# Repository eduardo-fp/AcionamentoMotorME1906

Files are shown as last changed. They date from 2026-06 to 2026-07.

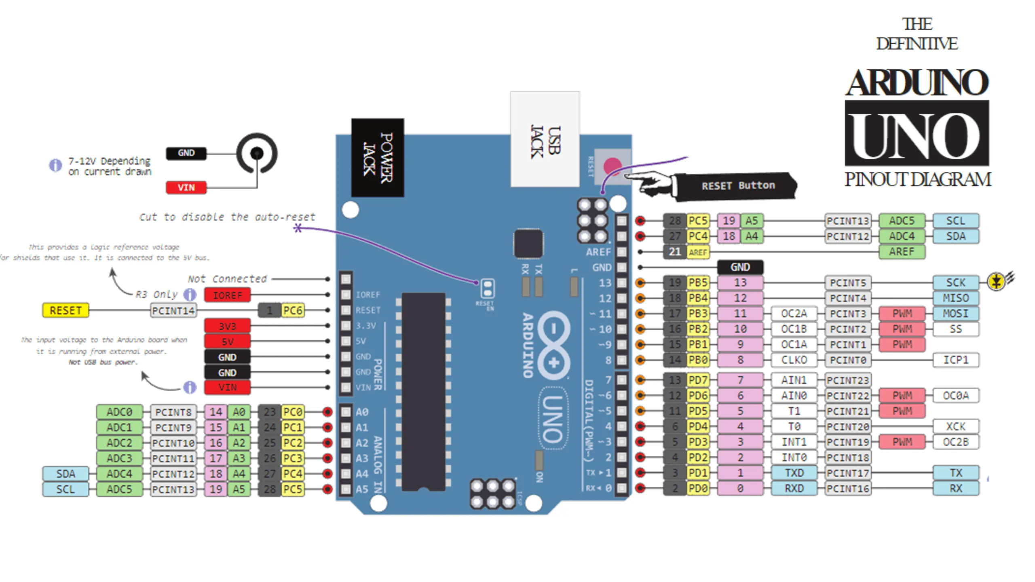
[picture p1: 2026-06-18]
Docs/ArduinoPinout.png

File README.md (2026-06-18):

# 🚀 Arduino Full-Bridge Shield: Acionamento de Potência para Motor ME19006 (ME0909)

O objetivo principal é criar uma ponte completa (*Full-Bridge*) robusta e didática para realizar ensaios de eficiência e testes de técnicas avançadas de modulação chaveada no motor **ME19006 (ME0909)**, utilizado no barco da equipe de corrida **Zênite Solar (IFSC)**.

A arquitetura foi pensada em formato Shield para o ecossistema Arduino, facilitando a troca rápida de códigos de controle e aquisição de dados durante as bancadas de teste.

## 📋 Especificações do Sistema

O projeto foi dimensionado para operar nas condições reais de teste da equipe de barco solar, trabalhando com alta margem de segurança elétrica e térmica:

| **Parâmetro / Componente** | **Especificação** | **Descrição / Justificativa** |
| :--- | :--- | :--- |
| **Tensão de Barramento** | `60V DC` | Tensão nominal de alimentação do barramento de tração do barco da equipe **Zênite Solar (IFSC)**. |
| **Corrente Máxima** | `50A` | Corrente máxima de teste estipulada para validação das modulações do TCC. |
| **Motor Alvo** | `ME19006 (ME0909)` | Motor utilizado no barco da equipe Zenite Solar (IFSC). |
| **Gate Driver** | `MP1923` | Driver Half-Bridge de 100V. Fornece 7A/8A de pico. |
| **MOSFET de Potência** | `IXFN420N10T` | MOSFET utilizado no barco da equipe Zenite Solar(IFSC). |
| **Frequência de Chaveamento** | `6 kHz a 12 kHz` | Faixa de frequência de modulação otimizada para o motor e para minimizar perdas no driver. |

## 🛡️ Destaques de Projeto da PCB

Para garantir que a placa funcione de forma estável sob correntes de 50A e barramento de 60V, as seguintes proteções e metodologias foram implementadas no layout:

1. **Rede de Bootstrap Otimizada:** Dimensionada utilizando o pior caso de chaveamento (**6 kHz**). Capacitores cerâmicos SMD de **4.7 µF (50V X7R)** foram selecionados para compensar as correntes quiescentes do driver e a perda de capacitância por efeito de *DC Bias*.

2. **Filtros Snubber RC:** Integrados fisicamente rentes aos drenos e fontes dos MOSFETs IXFN420N10T para mitigar os picos de sobretensão causados pela indutância parasita das trilhas na comutação.

3. **Dimensionamento de Trilhas de Potência:** Áreas de cobre superdimensionadas e estanhadas para suportar a densidade de corrente de 50A sem elevação excessiva de temperatura (calculado via IPC-2152).

## 📂 Estrutura do Repositório

O repositório está organizado para facilitar a replicação, fabricação e auditoria do projeto:

```text
📦 AcionamentoMotorME1906
 ┣ 📂 Hardware
 ┃ ┣ 📜 Esquemático (Arquivos fontes e PDF)
 ┃ ┣ 📜 PCB Layout (Arquivos de design e Gerbers para fabricação)
 ┃ ┣ 📜 BOM_Custos.csv (Lista de Materials e Orçamento do Projeto)
 ┃ ┗ 📜 Modelos 3D (Arquivos STEP para integração mecânica do Shield)
 ┣ 📂 Docs
 ┃ ┣ 📜 Calculos (Bootstrap, Snubber e dimensionamento de trilhas)
 ┃ ┗ 📜 Datasheets (Documentações técnicas do MP1923 e IXFN420N10T)
 ┣ 📂 Software
 ┃ ┗ 📜 Codigos Arduino (Implementação das rotinas de controle e PWM)
 ┗ 📜 README.md

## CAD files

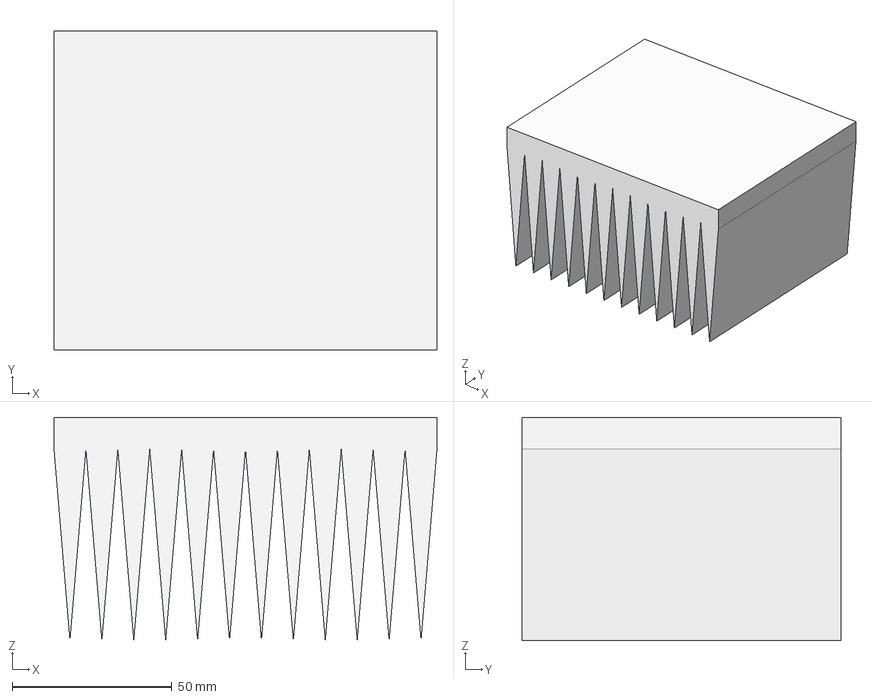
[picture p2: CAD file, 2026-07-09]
Biblioteca/DissipadorBarco.step
120.0 x 100.0 x 70.0 mm

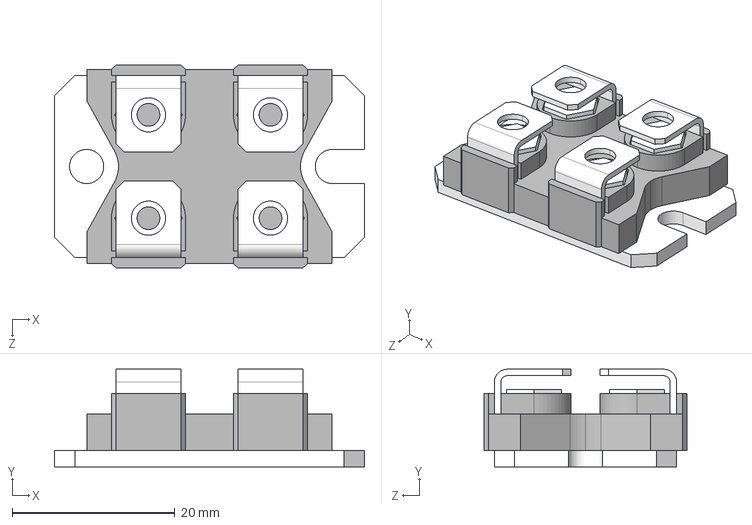
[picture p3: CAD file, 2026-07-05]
Biblioteca/User Library-SOT-227B.step
38.1 x 12.0 x 24.9 mm

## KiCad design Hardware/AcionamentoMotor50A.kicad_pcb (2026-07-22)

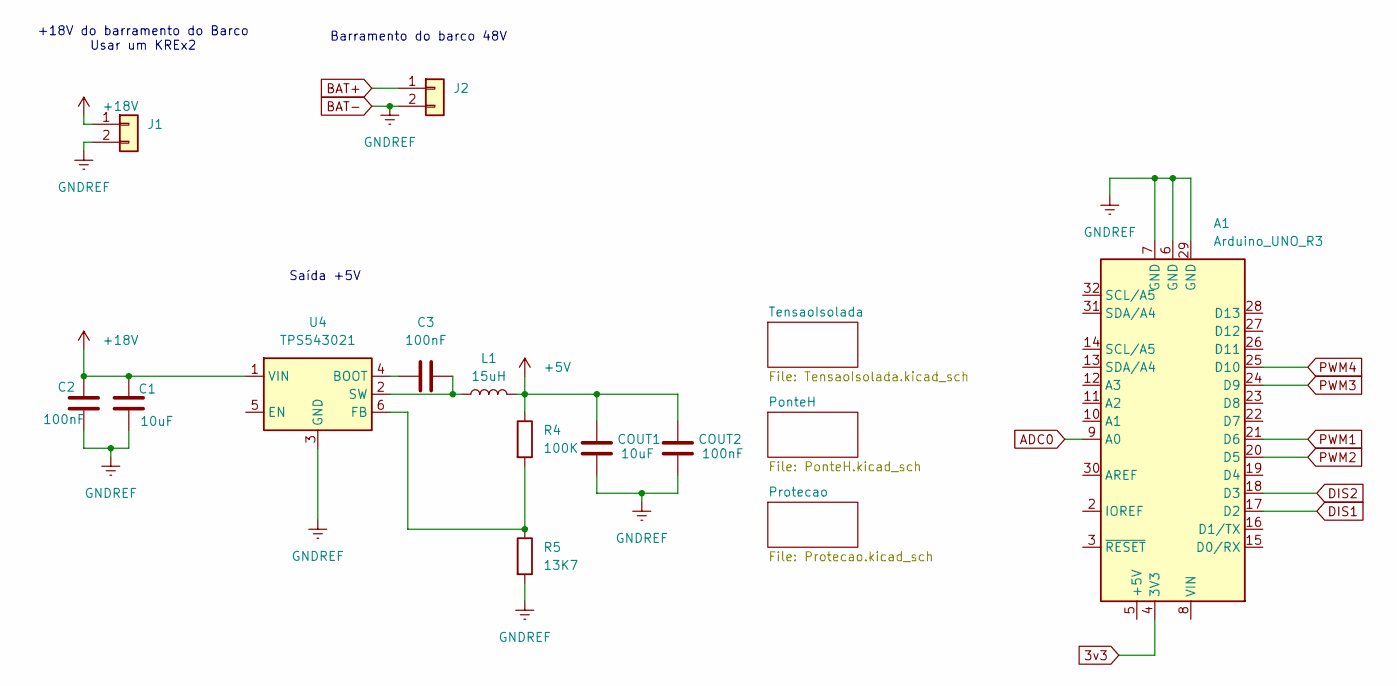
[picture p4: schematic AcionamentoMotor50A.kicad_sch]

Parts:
A1: Arduino_UNO_R3
C1: 10uF; C_0805_2012Metric_Pad1.18x1.45mm_HandSolder
C2, C3: 100nF; C_0805_2012Metric_Pad1.18x1.45mm_HandSolder
COUT1: 10uF; C_0805_2012Metric_Pad1.18x1.45mm_HandSolder
COUT2: 100nF; C_0805_2012Metric_Pad1.18x1.45mm_HandSolder
J1, J2: Conn_01x02; TerminalBlock_Phoenix_MKDS-1,5-2_1x02_P5.00mm_Horizontal
L1: 15uH; L_0805_2012Metric_Pad1.05x1.20mm_HandSolder
R4: 100K; R_0805_2012Metric_Pad1.20x1.40mm_HandSolder
R5: 13K7; R_0805_2012Metric_Pad1.20x1.40mm_HandSolder
U4: TPS543021; SOT-563

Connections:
3v3: A1.4 (3V3)
5V: COUT1.2, COUT2.2, L1.2, R4.1; also elsewhere on the board
+18V: C1.1, C2.1, J1.1, U4.1 (VIN); also elsewhere on the board
ADC0: A1.9 (A0); also elsewhere on the board
BAT+: J2.1; also elsewhere on the board
BAT-: A1.6 (GND), A1.7 (GND), A1.29 (GND), C1.2, C2.2, COUT1.1, COUT2.1, J1.2, J2.2, R5.2, U4.3 (GND); also elsewhere on the board
DIS1: A1.17 (D2); also elsewhere on the board
DIS2: A1.18 (D3); also elsewhere on the board
unnamed: C3.1, U4.4 (BOOT)
unnamed: R4.2, R5.1, U4.6 (FB)
unnamed: C3.2, L1.1, U4.2 (SW)
PWM1: A1.21 (D6); also elsewhere on the board
PWM2: A1.20 (D5); also elsewhere on the board
PWM3: A1.24 (D9); also elsewhere on the board
PWM4: A1.25 (D10); also elsewhere on the board

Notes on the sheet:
Saída +5V
Barramento do barco 48V
+18V do barramento do Barco Usar um KREx2

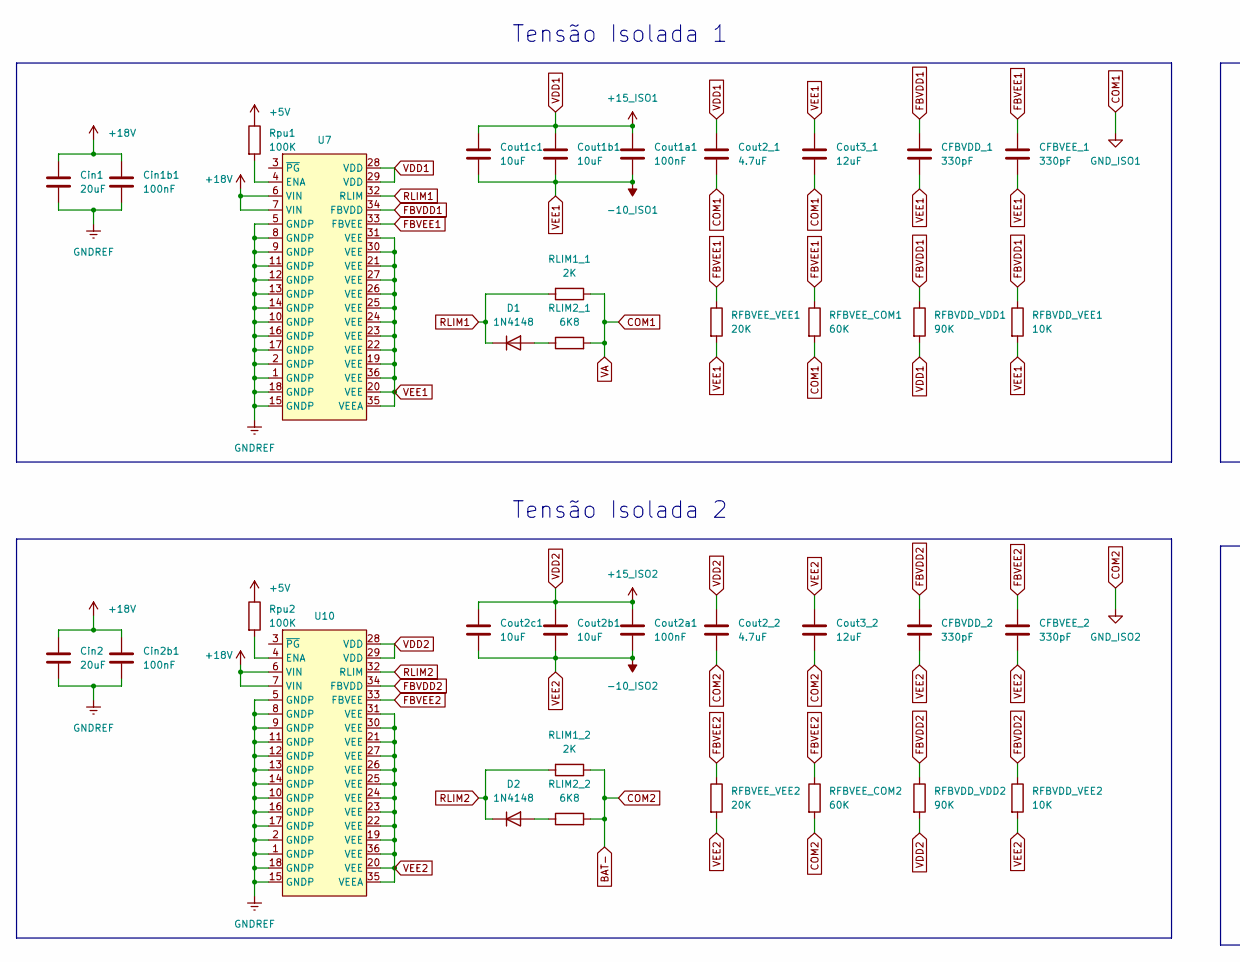
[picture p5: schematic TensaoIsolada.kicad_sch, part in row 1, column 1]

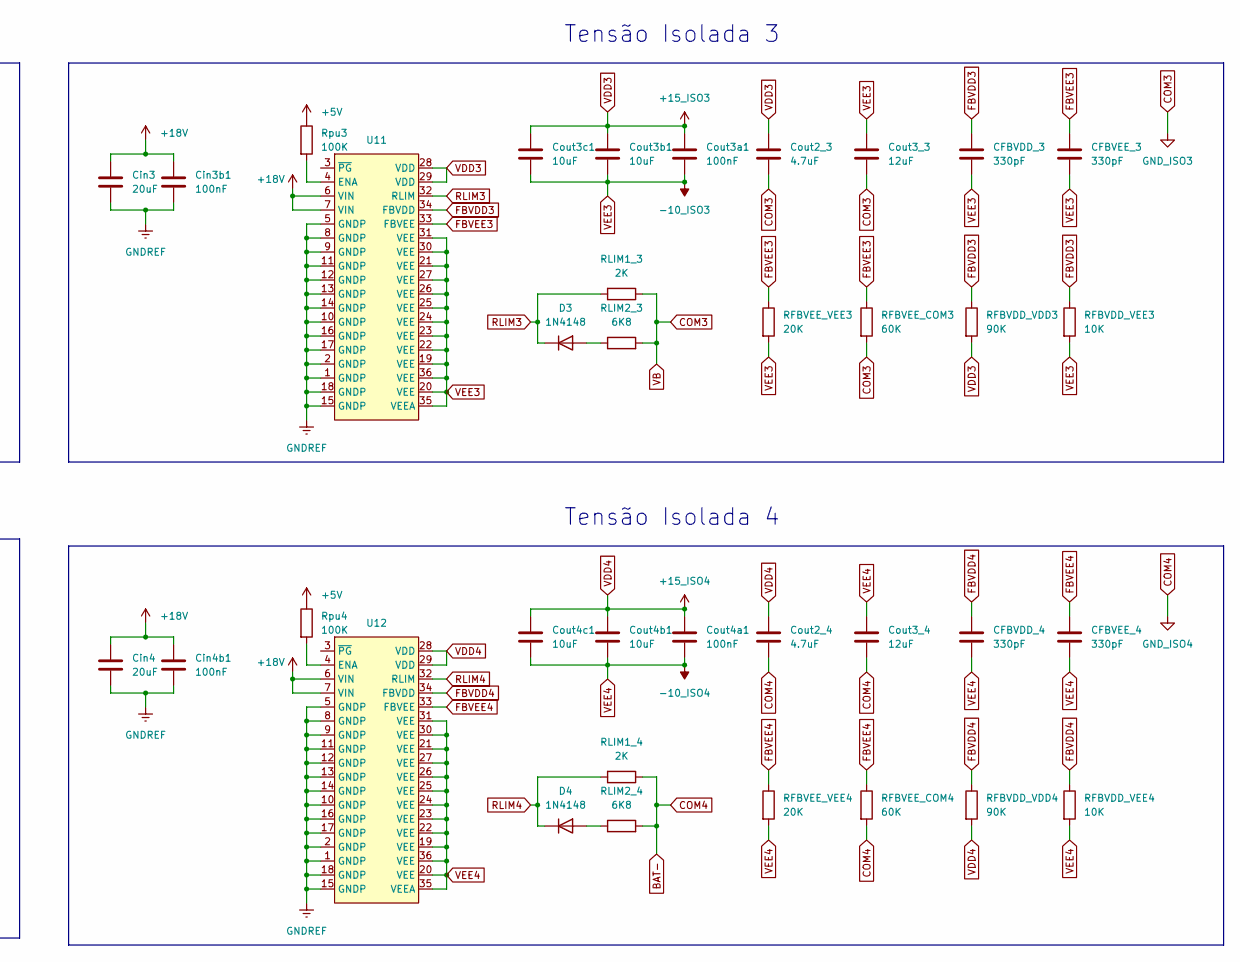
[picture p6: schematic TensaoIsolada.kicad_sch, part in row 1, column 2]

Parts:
CFBVDD_1, CFBVDD_2, CFBVDD_3, CFBVDD_4: 330pF; C_0805_2012Metric_Pad1.18x1.45mm_HandSolder
CFBVEE_1, CFBVEE_2, CFBVEE_3, CFBVEE_4: 330pF; C_0805_2012Metric_Pad1.18x1.45mm_HandSolder
Cin1, Cin2, Cin3, Cin4: 20uF; C_0805_2012Metric_Pad1.18x1.45mm_HandSolder
Cin1b1, Cin2b1, Cin3b1, Cin4b1: 100nF; C_0805_2012Metric_Pad1.18x1.45mm_HandSolder
Cout1a1, Cout2a1, Cout3a1, Cout4a1: 100nF; C_0805_2012Metric_Pad1.18x1.45mm_HandSolder
Cout1b1, Cout1c1, Cout2b1, Cout2c1, Cout3b1, Cout3c1, Cout4b1, Cout4c1: 10uF; C_0805_2012Metric_Pad1.18x1.45mm_HandSolder
Cout2_1, Cout2_2, Cout2_3, Cout2_4: 4.7uF; C_0805_2012Metric_Pad1.18x1.45mm_HandSolder
Cout3_1, Cout3_2, Cout3_3, Cout3_4: 12uF; C_0805_2012Metric_Pad1.18x1.45mm_HandSolder
D1, D2, D3, D4: 1N4148; D_DO-35_SOD27_P7.62mm_Horizontal
RFBVDD_VDD1, RFBVDD_VDD2, RFBVDD_VDD3, RFBVDD_VDD4: 90K; R_0805_2012Metric_Pad1.20x1.40mm_HandSolder
RFBVDD_VEE1, RFBVDD_VEE2, RFBVDD_VEE3, RFBVDD_VEE4: 10K; R_0805_2012Metric_Pad1.20x1.40mm_HandSolder
RFBVEE_COM1, RFBVEE_COM2, RFBVEE_COM3, RFBVEE_COM4: 60K; R_0805_2012Metric_Pad1.20x1.40mm_HandSolder
RFBVEE_VEE1, RFBVEE_VEE2, RFBVEE_VEE3, RFBVEE_VEE4: 20K; R_0805_2012Metric_Pad1.20x1.40mm_HandSolder
RLIM1_1, RLIM1_2, RLIM1_3, RLIM1_4: 2K; R_0805_2012Metric_Pad1.20x1.40mm_HandSolder
RLIM2_1, RLIM2_2, RLIM2_3, RLIM2_4: 6K8; R_0805_2012Metric_Pad1.20x1.40mm_HandSolder
Rpu1, Rpu2, Rpu3, Rpu4: 100K; R_0805_2012Metric_Pad1.20x1.40mm_HandSolder
U7, U10, U11, U12: SSOP-36

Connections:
5V: Rpu1.1, Rpu2.1, Rpu3.1, Rpu4.1; also elsewhere on the board
+18V: Cin1.1, Cin1b1.1, Cin2.1, Cin2b1.1, Cin3.1, Cin3b1.1, Cin4.1, Cin4b1.1, U7.6 (VIN), U7.7 (VIN), U10.6 (VIN), U10.7 (VIN), U11.6 (VIN), U11.7 (VIN), U12.6 (VIN), U12.7 (VIN); also elsewhere on the board
BAT-: Cin1.2, Cin1b1.2, Cin2.2, Cin2b1.2, Cin3.2, Cin3b1.2, Cin4.2, Cin4b1.2, Cout2_2.2, Cout2_4.2, Cout3_2.2, Cout3_4.2, RFBVEE_COM2.2, RFBVEE_COM4.2, RLIM1_2.1, RLIM1_4.1, RLIM2_2.2, RLIM2_4.2, U7.1 (GNDP), U7.2 (GNDP), U7.5 (GNDP), U7.8 (GNDP), U7.9 (GNDP), U7.10 (GNDP), U7.11 (GNDP), U7.12 (GNDP), U7.13 (GNDP), U7.14 (GNDP), U7.15 (GNDP), U7.16 (GNDP), U7.17 (GNDP), U7.18 (GNDP), U10.1 (GNDP), U10.2 (GNDP), U10.5 (GNDP), U10.8 (GNDP), U10.9 (GNDP), U10.10 (GNDP), U10.11 (GNDP), U10.12 (GNDP), U10.13 (GNDP), U10.14 (GNDP), U10.15 (GNDP), U10.16 (GNDP), U10.17 (GNDP), U10.18 (GNDP), U11.1 (GNDP), U11.2 (GNDP), U11.5 (GNDP), U11.8 (GNDP), U11.9 (GNDP), U11.10 (GNDP), U11.11 (GNDP), U11.12 (GNDP), U11.13 (GNDP), U11.14 (GNDP), U11.15 (GNDP), U11.16 (GNDP), U11.17 (GNDP), U11.18 (GNDP), U12.1 (GNDP), U12.2 (GNDP), U12.5 (GNDP), U12.8 (GNDP), U12.9 (GNDP), U12.10 (GNDP), U12.11 (GNDP), U12.12 (GNDP), U12.13 (GNDP), U12.14 (GNDP), U12.15 (GNDP), U12.16 (GNDP), U12.17 (GNDP), U12.18 (GNDP); also elsewhere on the board
COM1: Cout2_1.2, Cout3_1.2, RFBVEE_COM1.2, RLIM1_1.1, RLIM2_1.2; also elsewhere on the board
COM3: Cout2_3.2, Cout3_3.2, RFBVEE_COM3.2, RLIM1_3.1, RLIM2_3.2; also elsewhere on the board
FBVDD1: CFBVDD_1.1, RFBVDD_VDD1.1, RFBVDD_VEE1.1, U7.34 (FBVDD)
FBVDD2: CFBVDD_2.1, RFBVDD_VDD2.1, RFBVDD_VEE2.1, U10.34 (FBVDD)
FBVDD3: CFBVDD_3.1, RFBVDD_VDD3.1, RFBVDD_VEE3.1, U11.34 (FBVDD)
FBVDD4: CFBVDD_4.1, RFBVDD_VDD4.1, RFBVDD_VEE4.1, U12.34 (FBVDD)
FBVEE1: CFBVEE_1.1, RFBVEE_COM1.1, RFBVEE_VEE1.1, U7.33 (FBVEE)
FBVEE2: CFBVEE_2.1, RFBVEE_COM2.1, RFBVEE_VEE2.1, U10.33 (FBVEE)
FBVEE3: CFBVEE_3.1, RFBVEE_COM3.1, RFBVEE_VEE3.1, U11.33 (FBVEE)
FBVEE4: CFBVEE_4.1, RFBVEE_COM4.1, RFBVEE_VEE4.1, U12.33 (FBVEE)
unnamed: D1.2 (A), RLIM2_1.1
unnamed: D2.2 (A), RLIM2_2.1
unnamed: D3.2 (A), RLIM2_3.1
unnamed: D4.2 (A), RLIM2_4.1
unnamed: Rpu1.2, U7.4 (ENA)
unnamed: Rpu2.2, U10.4 (ENA)
unnamed: Rpu3.2, U11.4 (ENA)
unnamed: Rpu4.2, U12.4 (ENA)
RLIM1: D1.1 (K), RLIM1_1.2, U7.32 (RLIM)
RLIM2: D2.1 (K), RLIM1_2.2, U10.32 (RLIM)
RLIM3: D3.1 (K), RLIM1_3.2, U11.32 (RLIM)
RLIM4: D4.1 (K), RLIM1_4.2, U12.32 (RLIM)
VDD1: Cout1a1.1, Cout1b1.1, Cout1c1.1, Cout2_1.1, RFBVDD_VDD1.2, U7.28 (VDD), U7.29 (VDD); also elsewhere on the board
VDD2: Cout2_2.1, Cout2a1.1, Cout2b1.1, Cout2c1.1, RFBVDD_VDD2.2, U10.28 (VDD), U10.29 (VDD); also elsewhere on the board
VDD3: Cout2_3.1, Cout3a1.1, Cout3b1.1, Cout3c1.1, RFBVDD_VDD3.2, U11.28 (VDD), U11.29 (VDD); also elsewhere on the board
VDD4: Cout2_4.1, Cout4a1.1, Cout4b1.1, Cout4c1.1, RFBVDD_VDD4.2, U12.28 (VDD), U12.29 (VDD); also elsewhere on the board
VEE1: CFBVDD_1.2, CFBVEE_1.2, Cout1a1.2, Cout1b1.2, Cout1c1.2, Cout3_1.1, RFBVDD_VEE1.2, RFBVEE_VEE1.2, U7.19 (VEE), U7.20 (VEE), U7.21 (VEE), U7.22 (VEE), U7.23 (VEE), U7.24 (VEE), U7.25 (VEE), U7.26 (VEE), U7.27 (VEE), U7.30 (VEE), U7.31 (VEE), U7.35 (VEEA), U7.36 (VEE); also elsewhere on the board
VEE2: CFBVDD_2.2, CFBVEE_2.2, Cout2a1.2, Cout2b1.2, Cout2c1.2, Cout3_2.1, RFBVDD_VEE2.2, RFBVEE_VEE2.2, U10.19 (VEE), U10.20 (VEE), U10.21 (VEE), U10.22 (VEE), U10.23 (VEE), U10.24 (VEE), U10.25 (VEE), U10.26 (VEE), U10.27 (VEE), U10.30 (VEE), U10.31 (VEE), U10.35 (VEEA), U10.36 (VEE); also elsewhere on the board
VEE3: CFBVDD_3.2, CFBVEE_3.2, Cout3_3.1, Cout3a1.2, Cout3b1.2, Cout3c1.2, RFBVDD_VEE3.2, RFBVEE_VEE3.2, U11.19 (VEE), U11.20 (VEE), U11.21 (VEE), U11.22 (VEE), U11.23 (VEE), U11.24 (VEE), U11.25 (VEE), U11.26 (VEE), U11.27 (VEE), U11.30 (VEE), U11.31 (VEE), U11.35 (VEEA), U11.36 (VEE); also elsewhere on the board
VEE4: CFBVDD_4.2, CFBVEE_4.2, Cout3_4.1, Cout4a1.2, Cout4b1.2, Cout4c1.2, RFBVDD_VEE4.2, RFBVEE_VEE4.2, U12.19 (VEE), U12.20 (VEE), U12.21 (VEE), U12.22 (VEE), U12.23 (VEE), U12.24 (VEE), U12.25 (VEE), U12.26 (VEE), U12.27 (VEE), U12.30 (VEE), U12.31 (VEE), U12.35 (VEEA), U12.36 (VEE); also elsewhere on the board

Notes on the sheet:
Tensão Isolada 4
Tensão Isolada 1
Tensão Isolada 2
Tensão Isolada 3

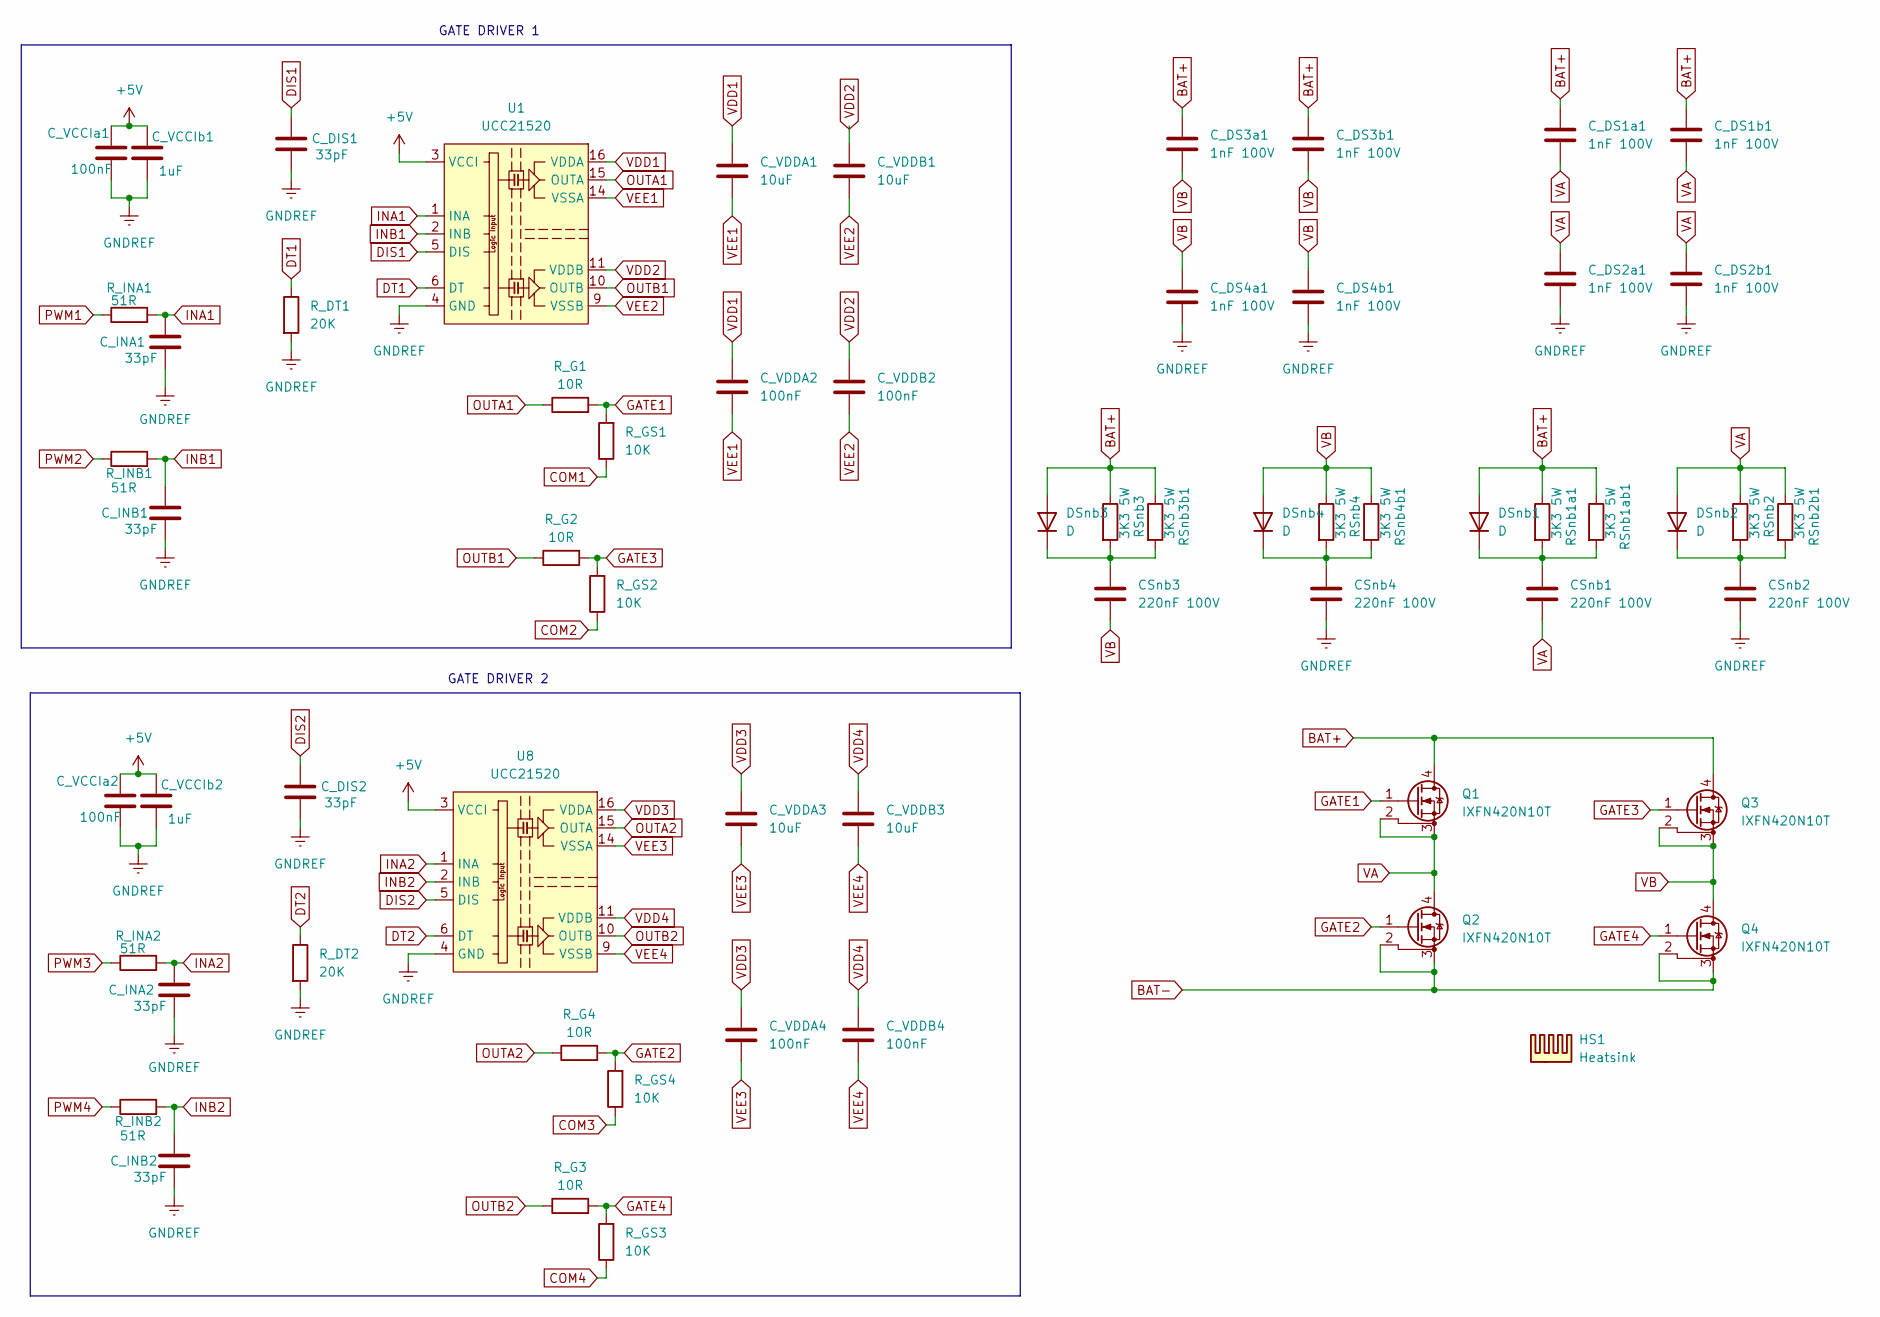
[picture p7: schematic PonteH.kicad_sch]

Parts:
CSnb1, CSnb2, CSnb3, CSnb4: 220nF 100V; C_Axial_L5.1mm_D3.1mm_P10.00mm_Horizontal
C_DIS1, C_DIS2: 33pF; C_0805_2012Metric_Pad1.18x1.45mm_HandSolder
C_DS1a1, C_DS1b1, C_DS2a1, C_DS2b1, C_DS3a1, C_DS3b1, C_DS4a1, C_DS4b1: 1nF 100V; C_0805_2012Metric_Pad1.18x1.45mm_HandSolder
C_INA1, C_INA2: 33pF; C_0805_2012Metric_Pad1.18x1.45mm_HandSolder
C_INB1, C_INB2: 33pF; C_0805_2012Metric_Pad1.18x1.45mm_HandSolder
C_VCCI a1, C_VCCI a2: 100nF; C_0805_2012Metric_Pad1.18x1.45mm_HandSolder
C_VCCI b1, C_VCCI b2: 1uF; C_0805_2012Metric_Pad1.18x1.45mm_HandSolder
C_VDDA1, C_VDDA3: 10uF; C_0805_2012Metric_Pad1.18x1.45mm_HandSolder
C_VDDA2, C_VDDA4: 100nF; C_0805_2012Metric_Pad1.18x1.45mm_HandSolder
C_VDDB1, C_VDDB3: 10uF; C_0805_2012Metric_Pad1.18x1.45mm_HandSolder
C_VDDB2, C_VDDB4: 100nF; C_0805_2012Metric_Pad1.18x1.45mm_HandSolder
DSnb1, DSnb2, DSnb3, DSnb4: D; D_SMA_Handsoldering
HS1: Heatsink; Heatsink_120mmx100mm_H70mm
Q1, Q2, Q3, Q4: IXFN420N10T; SOT-227
RSnb1a1, RSnb1ab1, RSnb2, RSnb2b1, RSnb3, RSnb3b1, RSnb4, RSnb4b1: 3K3 5W; R_Axial_Power_L25.0mm_W9.0mm_P27.94mm
R_DT1, R_DT2: 20K; R_0805_2012Metric_Pad1.20x1.40mm_HandSolder
R_G1, R_G2, R_G3, R_G4: 10R; R_0805_2012Metric_Pad1.20x1.40mm_HandSolder
R_GS1, R_GS2, R_GS3, R_GS4: 10K; R_0805_2012Metric_Pad1.20x1.40mm_HandSolder
R_INA1, R_INA2: 51R; R_0805_2012Metric_Pad1.20x1.40mm_HandSolder
R_INB1, R_INB2: 51R; R_0805_2012Metric_Pad1.20x1.40mm_HandSolder
U1, U8: UCC21520; SOIC-16W_7.5x10.3mm_P1.27mm

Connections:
5V: C_VCCI a1.1, C_VCCI a2.1, C_VCCI b1.1, C_VCCI b2.1, U1.3 (VCCI), U1.8 (VCCI), U8.3 (VCCI), U8.8 (VCCI); also elsewhere on the board
BAT+: C_DS1a1.1, C_DS1b1.1, C_DS3a1.1, C_DS3b1.1, DSnb1.2 (A), DSnb3.2 (A), Q1.4 (D), Q3.4 (D), RSnb1a1.1, RSnb1ab1.1, RSnb3.1, RSnb3b1.1; also elsewhere on the board
BAT-: CSnb2.2, CSnb4.2, C_DIS1.2, C_DIS2.2, C_DS2a1.2, C_DS2b1.2, C_DS4a1.2, C_DS4b1.2, C_INA1.2, C_INA2.2, C_INB1.2, C_INB2.2, C_VCCI a1.2, C_VCCI a2.2, C_VCCI b1.2, C_VCCI b2.2, Q2.2 (DS), Q2.3 (S), Q4.2 (DS), Q4.3 (S), R_DT1.2, R_DT2.2, R_GS2.1, R_GS3.1, U1.4 (GND), U8.4 (GND); also elsewhere on the board
COM1: CSnb1.2, C_DS1a1.2, C_DS1b1.2, C_DS2a1.1, C_DS2b1.1, DSnb2.2 (A), Q1.2 (DS), Q1.3 (S), Q2.4 (D), RSnb2.1, RSnb2b1.1, R_GS1.1; also elsewhere on the board
COM3: CSnb3.2, C_DS3a1.2, C_DS3b1.2, C_DS4a1.1, C_DS4b1.1, DSnb4.2 (A), Q3.2 (DS), Q3.3 (S), Q4.4 (D), RSnb4.1, RSnb4b1.1, R_GS4.1; also elsewhere on the board
DIS1: C_DIS1.1, U1.5 (DIS); also elsewhere on the board
DIS2: C_DIS2.1, U8.5 (DIS); also elsewhere on the board
DT1: R_DT1.1, U1.6 (DT)
DT2: R_DT2.1, U8.6 (DT)
GATE1: Q1.1 (G), R_G1.2, R_GS1.2
GATE2: Q2.1 (G), R_G4.2, R_GS4.2
GATE3: Q3.1 (G), R_G2.2, R_GS2.2
GATE4: Q4.1 (G), R_G3.2, R_GS3.2
INA1: C_INA1.1, R_INA1.2, U1.1 (INA)
INA2: C_INA2.1, R_INA2.2, U8.1 (INA)
INB1: C_INB1.1, R_INB1.2, U1.2 (INB)
INB2: C_INB2.1, R_INB2.2, U8.2 (INB)
unnamed: CSnb1.1, DSnb1.1 (K), RSnb1a1.2, RSnb1ab1.2
unnamed: CSnb2.1, DSnb2.1 (K), RSnb2.2, RSnb2b1.2
unnamed: CSnb3.1, DSnb3.1 (K), RSnb3.2, RSnb3b1.2
unnamed: CSnb4.1, DSnb4.1 (K), RSnb4.2, RSnb4b1.2
OUTA1: R_G1.1, U1.15 (OUTA)
OUTA2: R_G4.1, U8.15 (OUTA)
OUTB1: R_G2.1, U1.10 (OUTB)
OUTB2: R_G3.1, U8.10 (OUTB)
PWM1: R_INA1.1; also elsewhere on the board
PWM2: R_INB1.1; also elsewhere on the board
PWM3: R_INA2.1; also elsewhere on the board
PWM4: R_INB2.1; also elsewhere on the board
VDD1: C_VDDA1.1, C_VDDA2.1, U1.16 (VDDA); also elsewhere on the board
VDD2: C_VDDB1.1, C_VDDB2.1, U1.11 (VDDB); also elsewhere on the board
VDD3: C_VDDA3.1, C_VDDA4.1, U8.16 (VDDA); also elsewhere on the board
VDD4: C_VDDB3.1, C_VDDB4.1, U8.11 (VDDB); also elsewhere on the board
VEE1: C_VDDA1.2, C_VDDA2.2, U1.14 (VSSA); also elsewhere on the board
VEE2: C_VDDB1.2, C_VDDB2.2, U1.9 (VSSB); also elsewhere on the board
VEE3: C_VDDA3.2, C_VDDA4.2, U8.14 (VSSA); also elsewhere on the board
VEE4: C_VDDB3.2, C_VDDB4.2, U8.9 (VSSB); also elsewhere on the board

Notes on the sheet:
GATE DRIVER 1
GATE DRIVER 2

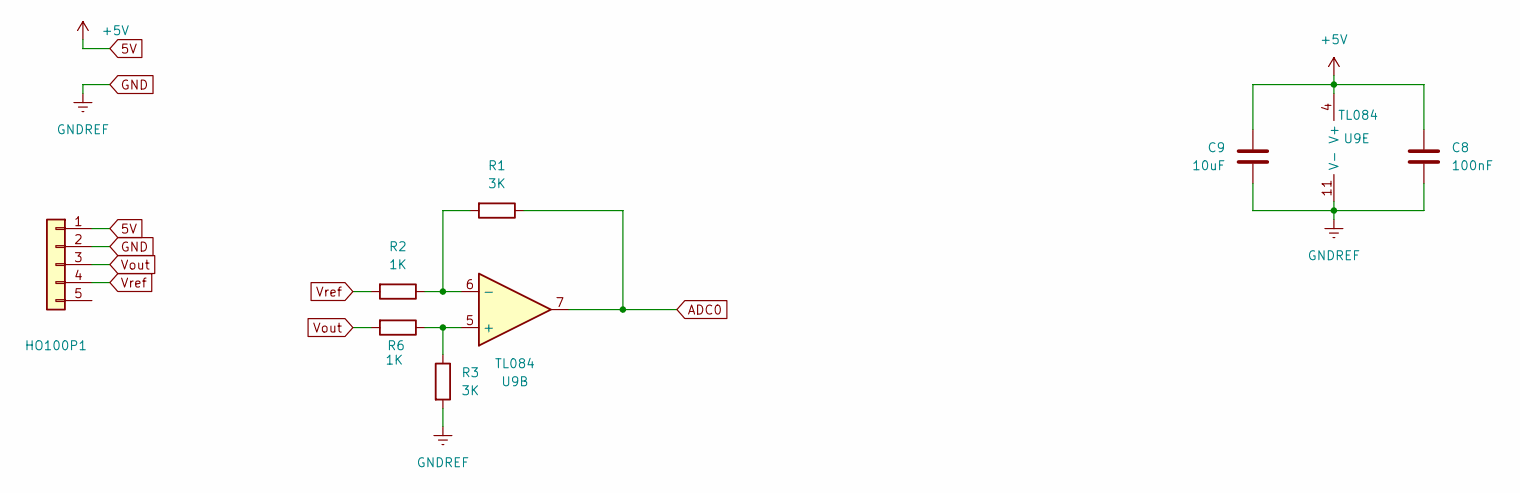
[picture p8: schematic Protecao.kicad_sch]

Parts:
C8: 100nF; C_0805_2012Metric_Pad1.18x1.45mm_HandSolder
C9: 10uF; C_0805_2012Metric_Pad1.18x1.45mm_HandSolder
HO100P1: Conn_01x05; Molex_KK-254_AE-6410-05A_1x05_P2.54mm_Vertical
R1, R3: 3K; R_0805_2012Metric_Pad1.20x1.40mm_HandSolder
R2, R6: 1K; R_0805_2012Metric_Pad1.20x1.40mm_HandSolder
U9: TL084; SOIC-14_3.9x8.7mm_P1.27mm

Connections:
5V: C8.1, C9.1, HO100P1.1, U9.4 (V+); also elsewhere on the board
ADC0: R1.1, U9.7; also elsewhere on the board
BAT-: C8.2, C9.2, HO100P1.2, R3.2, U9.11 (V-); also elsewhere on the board
unnamed: R3.1, R6.1, U9.5 (+)
unnamed: R1.2, R2.1, U9.6 (-)
Vout: HO100P1.3, R6.2
Vref: HO100P1.4, R2.2

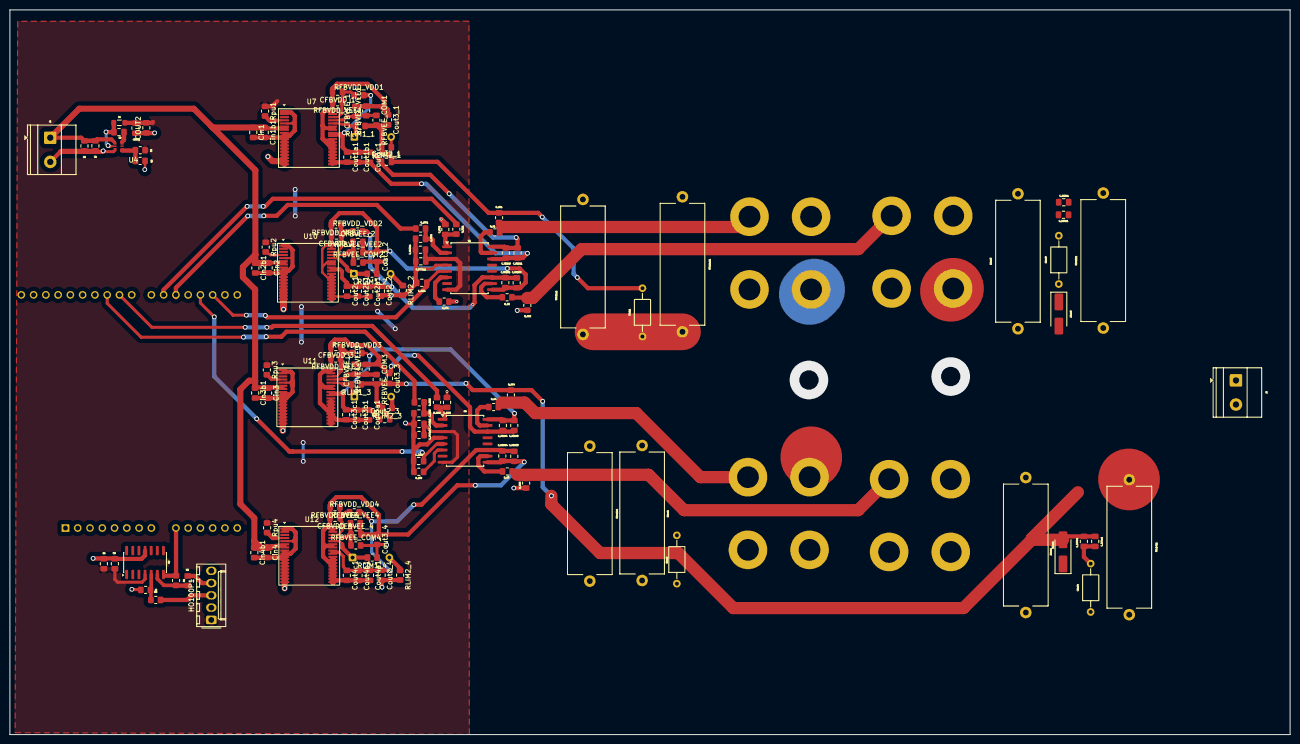
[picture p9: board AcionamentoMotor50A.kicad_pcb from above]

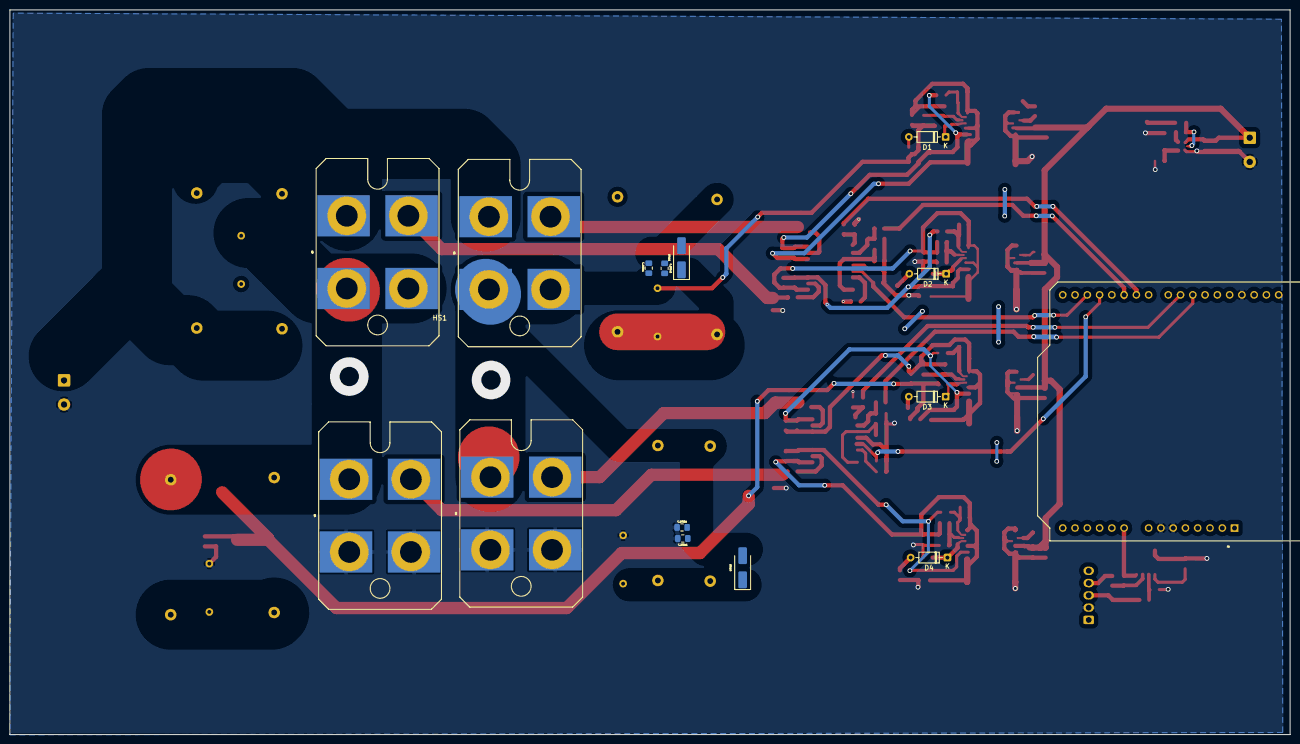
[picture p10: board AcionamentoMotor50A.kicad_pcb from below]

Board: 2 copper layers, 265.0 x 150.0 mm, 155 parts (16 on the bottom side), 66 nets.

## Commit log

2026-06-18 2026-06-18
    Commit da base do projeto
    [AcionamentoMotor50A.kicad_pcb, AcionamentoMotor50A.kicad_sch]
2026-06-18 2026_06_18
    Esquemático atualizado
    Foram colocados os snubbers, capacitores para controlar o tempo de subida (CDS) e capacitores para controlar o tempo em que o MOSFET abre e fecha (CGS)
    Falta calcular os snubbers e ajustar os valores dos capacitores
    [AcionamentoMotor50A.kicad_sch]
2026-06-25 2026_06_25
    adicionado o circuito para o MOSFET abrir mais rápido que ela fecha
    [AcionamentoMotor50A.kicad_sch]
2026-06-25 2026_06_25
    Esquemático finalizado.
    Footprints corrigidos
    [AcionamentoMotor50A.kicad_pcb, AcionamentoMotor50A.kicad_sch]
2026-07-02 2026_07_02
    Alterações no esquemático para não usar bootstrap... e inicializaçao do roteamento
    [AcionamentoMotor50A.kicad_pcb, AcionamentoMotor50A.kicad_sch, Braço1.kicad_sch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]
2026-07-02 roteamento de fonte isolada
    [AcionamentoMotor50A.kicad_pcb]
2026-07-03 2026_07_03
    Continuidade do roteamento..
    foram roteados os drivers
    [AcionamentoMotor50A.kicad_pcb, TensaoIsolada.kicad_sch]
2026-07-04 2026_07_04
    Todas as ligações foram feitas.
    Faltar rodar DRC
    Verificar as regras JLPCB
    [AcionamentoMotor50A.kicad_pcb, AcionamentoMotor50A.kicad_sch, Braço1.kicad_sch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]
2026-07-05 Ajustes do DRC. Removida a solder mask das trilhas de potência.
    [AcionamentoMotor50A.kicad_pcb]
2026-07-05 2026_07_05
    PCB Finalizada
    [AcionamentoMotor50A.kicad_pcb, User Library-SOT-227B.step]
2026-07-09 2026_07_09
    Feitas simulações da corrente do gate e escolha de um novo gate driver
    [AcionamentoMotor50A.kicad_sch, Braço1.kicad_sch, Braço2.kicad_sch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]
2026-07-22 2026_07_22
    Finalizada a PCB para fazer na fresa do IFSC
    [AcionamentoMotor50A.kicad_pcb, AcionamentoMotor50A.kicad_sch, Braço1.kicad_sch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]
